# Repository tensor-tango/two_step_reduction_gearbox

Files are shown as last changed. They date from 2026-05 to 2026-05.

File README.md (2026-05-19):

# Project Overview
This project was developed as a portfolio engineering case study to demonstrate practical CAD design skills, mechanical reasoning and the ability to create employer-relevant engineering documentation.
The purpose of this project is not only to show a 3D model, but to demonstrate the practical value I can bring as an employee: designing mechanical parts, creating structured CAD assemblies, preparing technical drawings, documenting design assumptions, organizing a bill of materials and communicating engineering decisions clearly.
Used software: SOLIDWORKS

Below is the kinematic demonstration of the gearbox, with initial pinion speed of 100rpm
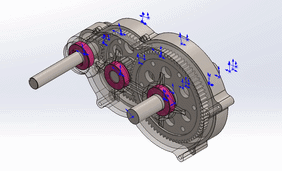
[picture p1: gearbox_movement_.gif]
Kinematics_demo


Below is one of the screenshots, which demonstrates the exploded view of the gearbox
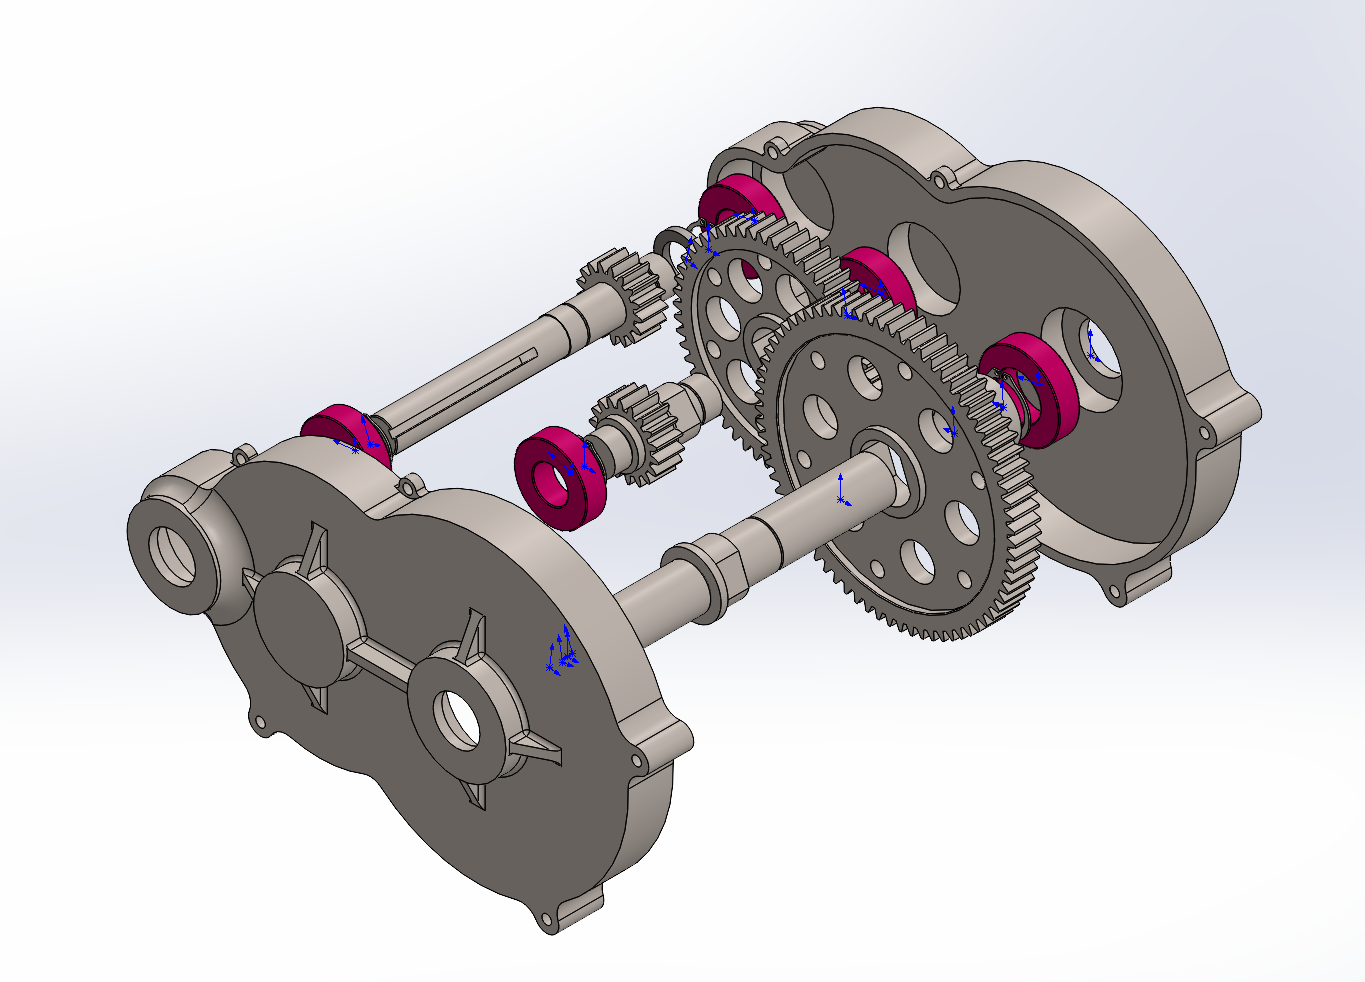
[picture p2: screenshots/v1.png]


Below is one of the blueprints, which demonstrates the technical drawing of lower housing part
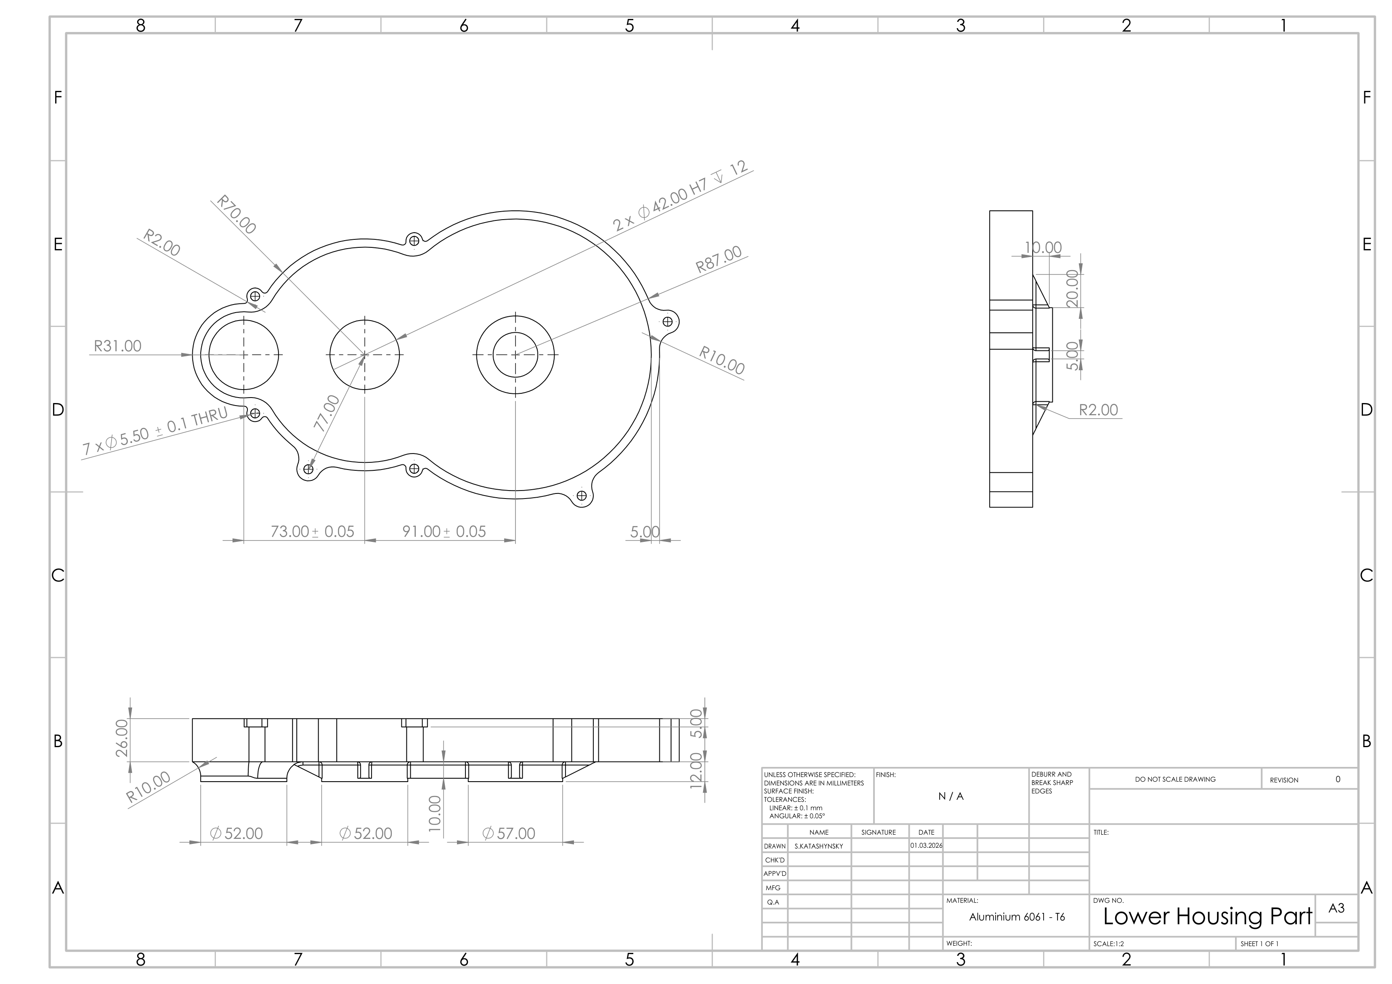
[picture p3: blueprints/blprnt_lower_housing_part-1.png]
Blueprint_demo


# Technical Notice
1. Actual bearings were replaced to the simplified bearing placeholders based on standard envelope dimensions
2. Material is assigned for CAD visualization only. Final material selection was not part of this study.
3. Actual ratio of the gearbox is 13.36:1, which gives 2.77% deviation from the target ratio
4. Normal internal clearance, standard precision and concept-level material assumptions were used.
5. Tight-fit for housing fastener bolts was assumed
6. Lubrication assumption: Lithium-EP 2

# BOM (Bill Of Materials)
| Item No. | Part Name | File Name | Qty. | Category | Material / Assumption | Notes |
|---:|---|---|---:|---|---|---|
| 1 | Lower housing part | `lower_part.SLDPRT` | 1 | Custom designed part | Aluminum 6061-T6 / aluminum alloy | Lower half of split gearbox housing |
| 2 | Upper housing part | `upper_part.SLDPRT` | 1 | Custom designed part | Aluminum 6061-T6 / aluminum alloy | Upper half of split gearbox housing |
| 3 | Gear A / input pinion, 17T | `gear_a.SLDPRT` | 1 | Custom gear | C45 steel / AISI 1045 steel | First-stage driving pinion, module 2 |
| 4 | Gear B / first-stage driven gear, 56T | `gear_b.SLDPRT` | 1 | Custom gear | C45 steel / AISI 1045 steel | First-stage driven gear, module 2 |
| 5 | Gear C / second-stage pinion, 18T | `gear_c.SLDPRT` | 1 | Custom gear | C45 steel / AISI 1045 steel | Second-stage driving pinion, module 2 |
| 6 | Gear D / output gear, 73T | `gear_d.SLDPRT` | 1 | Custom gear | C45 steel / AISI 1045 steel | Second-stage output gear, module 2 |
| 7 | Output shaft | `output_shaft.SLDPRT` | 1 | Custom shaft | C45 steel / AISI 1045 steeld | Supports output gear and transmits output torque |
| 8 | Output shaft spacer tube | `output_shaft_stopper_tube.SLDPRT` | 1 | Custom spacer | C45 steel / AISI 1045 steel | Axial positioning component |
| 9 | Third gear shaft spacer tube | `a_gear_shaft_stopper_tube.SLDPRT` | 1 | Custom spacer | C45 steel / AISI 1045 steel | Axial positioning component for intermediate shaft |
| 10 | Bearing placeholder 6004 | `cosmetic_bearing_20-42-12.SLDPRT` | 4 | Simplified standard component | Bearing steel | Standard envelope: 20×42×12 mm, CN |
| 11 | Bearing placeholder 6005 | `cosmetic_bearing_25-47-12.SLDPRT` | 4 | Simplified standard component | Bearing steel | Standard envelope: 25×47×12 mm, CN |
| 12 | Retaining ring for 20 mm shaft, DIN471 | `retaining_ring_1.SLDPRT` | 4 | Simplified standard component | Spring steel | Used for axial retention |
| 13 | Retaining ring for 25 mm shaft, DIN 471 | `retaining_ring_2.SLDPRT` | 2 | Simplified standard component | Spring steel | Used for axial retention |
| 14 | M5 hex head bolt | | 7 | Standard hardware | Steel, class 8.8, zinc-plated | Used to fasten upper and lower housing parts |
| 15 | M5 washer | |14 | Standard hardware | Steel, zinc-plated | Optional washer under bolt head |
| 16 | M5 hex nut | | 7 | Standard hardware | Steel, class 8.8,  zinc-plated | Required if the lower housing is not threaded |

# FEM-Studies
A simplified static FEM study was performed to visualize stress concentration in the gear tooth contact regions.
All of the gears were assigned to the material of "Plain Carbon Steel".

Below is one of the screenshots, which demonstrates the local tooth - stress conecetration for the first stage of the gearbox
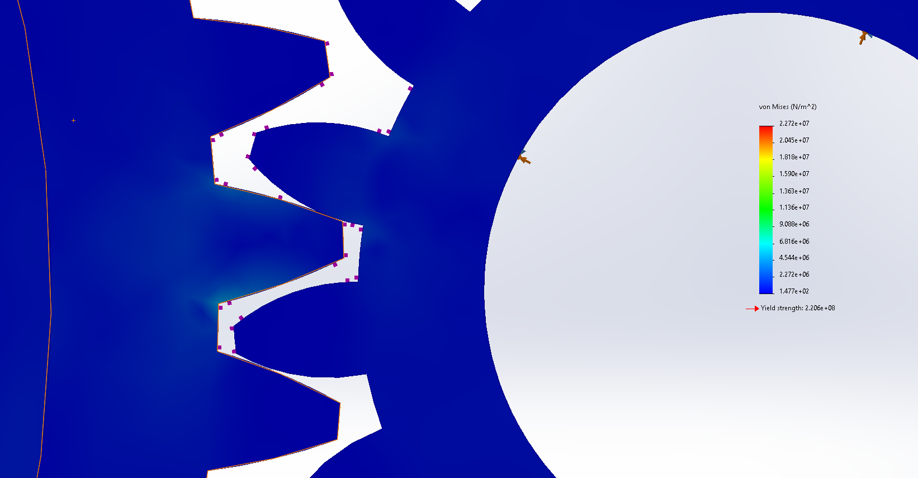
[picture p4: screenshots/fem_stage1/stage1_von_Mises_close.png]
Stress in stage 1


Below is one of the screenshots, which demonstrates the local tooth-stress conecetration for the second stage of the gearbox
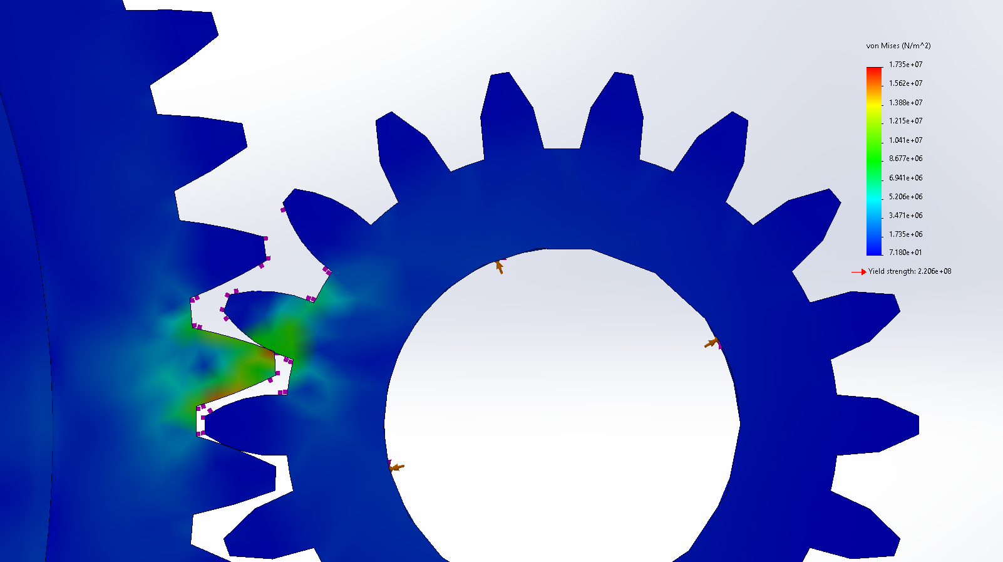
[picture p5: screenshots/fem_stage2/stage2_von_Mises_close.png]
Stress in stage 2


The full-view screenshots with the results of FEM-study for both of the stage can be found in './screenshots' folder. They include stress-concentration, displacement and strain.

| FEM Case | Load setup | Max von Mises | Yield strength | Safety Factor (FoS) |
|---|---|---|---|---|
| Stage 1 | 1 $N\cdot m$ torque on Gear A, Gear B constrained | 22.7 MPa | 220.6MPa | 9.7 |
| Stage 2 | 3.13 $N\cdot m$ torque on Gear C, Gear D constrained | 17.4 MPa | 220.6 MPa | 12.7 |

It was assumed the input torque 1 $N\cdot m$ on Gear A, so that in the second stage the Gear C has torque approx 3.13 $N\cdot m$.
According to this study, the maximal input torque could be  9.7 $N\cdot m$.
Below is the table of different possible input torques and safety levels

| Safety Factor (FoS) | Input Torque |
| --- | --- |
| FoS 1.0 | 9.7 $N\cdot m$ |
| FoS 1.5 | 6.5 $N \cdot m$ |
| FoS 2.0 | 4.85 $N \cdot m$ |
| FoS 3.0 | 3.2 $N\cdot m$|
| FoS 5.0| 1.9 $N\cdot m$ |

These FEM studies are simplified static torque/contact checks

# Bearings information
The bearing geometry in this project is simplified and used as placeholder geometry for CAD layout purposes.
The selected envelope dimensions correspond to standard deep groove ball bearings:
1. 6004: 20×42×12 mm
2. 6005: 25×47×12 mm

# Calculations
Gear ratio:
- Stage 1: 56 / 17 = 3.294
- Stage 2: 73 / 18 = 4.056
- Total ratio: 3.294 $\cdot$ 4.056 = 13.36:1
- Deviation from target 13:1 = +2.77%

Pitch diameter:
- $dA = 2 \cdot 17 = 34$ mm
- $dB = 2 \cdot 56 = 112$ mm
- $dC = 2 \cdot 18 = 36$ mm
- $dD = 2 \cdot 73 = 146$ mm

Center distances:
- $a_1 = \frac{dA + dB}{2} = \frac{34 + 112}{2} = 73$ mm
- $a_2 = \frac{dC + dD}{2} = \frac{36 + 146}{2} = 91$ mm

Output speed:
- $n_{out} = 100 / 13.36 = 7.485$ rpm

Simplified tangential tooth load estimation:
Assumption of Input Torque as $1Nm$
- $F_{tA} = 2 \cdot 1 / 0.034 = 58.8$ N
- $T_{intermediate} = 1 \cdot 3.294 \cdot 0.95 = 3.13$ Nm
- $F_{tC} = 2 × 3.13 / 0.036 = 173.9$ N

Radial gear force estimation:
- $F_{rA} = 58.8 \cdot tan(20°) = 21.4$ N
- $F_{rC} = 173.9 \cdot tan(20°) = 63.3$ N

Bearing reaction estimation (for the second stage):
- $F_{res} = (173.9² + 63.3²)^{1/2} = 185.1$ N

# Gears Info
Dimension are specified in mm and deg

Gear A (pinion):
1. No. of Teeth: 17
2. Module: 2
3. Pressure Angle: 20
4. Pitch diameter: 34
5. Outside diameter: 38
6. Root diameter: 29
7. Base diameter: 31.95
8. Face width: 15

Gear B:
1. No. of Teeth: 56
2. Module: 2
3. Pressure Angle: 20
4. Pitch diameter: 112
5. Outside diameter: 116
6. Root diameter: 107
7. Base diameter: 107
8. Face width: 15

Gear C:
1. No. of Teeth: 18
2. Module: 2
3. Pressure Angle: 20
4. Pitch diameter: 36
5. Outside diameter: 40
6. Root diameter: 31
7. Base diameter: 33.825
8. Face width: 15

Gear D:
1. No. of Teeth: 73
2. Module: 2
3. Pressure Angle: 20
4. Pitch diameter: 146
5. Outside diameter: 150
6. Root diameter: 140.98
7. Base diameter: 137.2
8. Face width: 15

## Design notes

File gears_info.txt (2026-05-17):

Dimension are specified in mm and deg

Gear A (pinion):
	No. of Teeth: 17
	Module: 2
	Pressure Angle: 20
	Pitch diameter: 34
	Outside diameter: 38
	Root diameter: 29
	Base diameter: 31.95
	Face width: 15

Gear B:
	No. of Teeth: 56
	Module: 2
	Pressure Angle: 20
	Pitch diameter: 112
	Outside diameter: 116
	Root diameter: 107
	Base diameter: 107
	Face width: 15

Gear C:
	No. of Teeth: 18
	Module: 2
	Pressure Angle: 20
	Pitch diameter: 36
	Outside diameter: 40
	Root diameter: 31
	Base diameter: 33.825
	Face width: 15

Gear D:
	No. of Teeth: 73
	Module: 2
	Pressure Angle: 20
	Pitch diameter: 146
	Outside diameter: 150
	Root diameter: 140.98
	Base diameter: 137.2
	Face width: 15

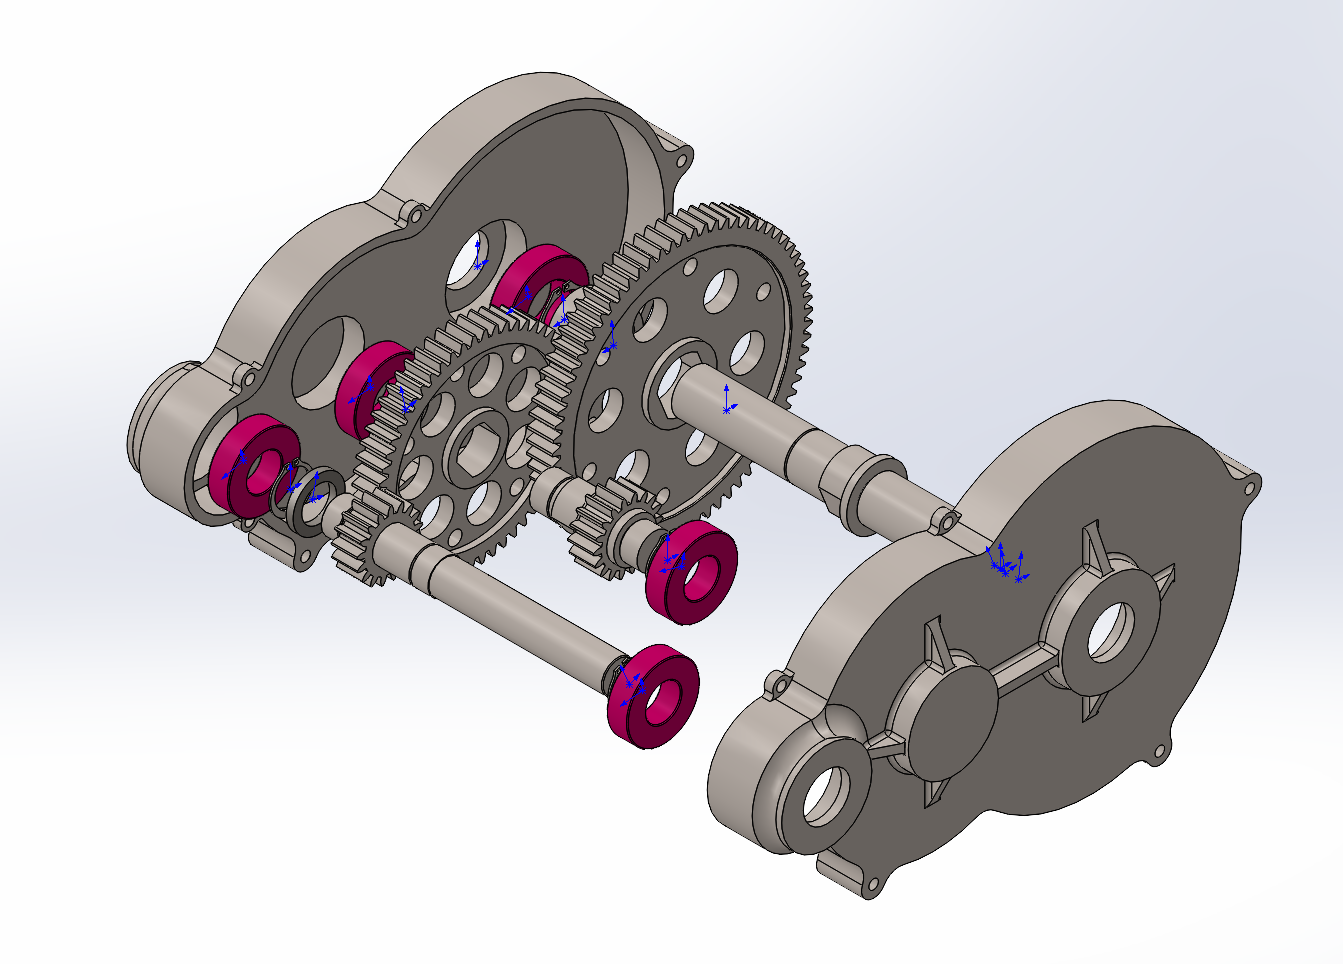
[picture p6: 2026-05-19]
screenshots/v3.png

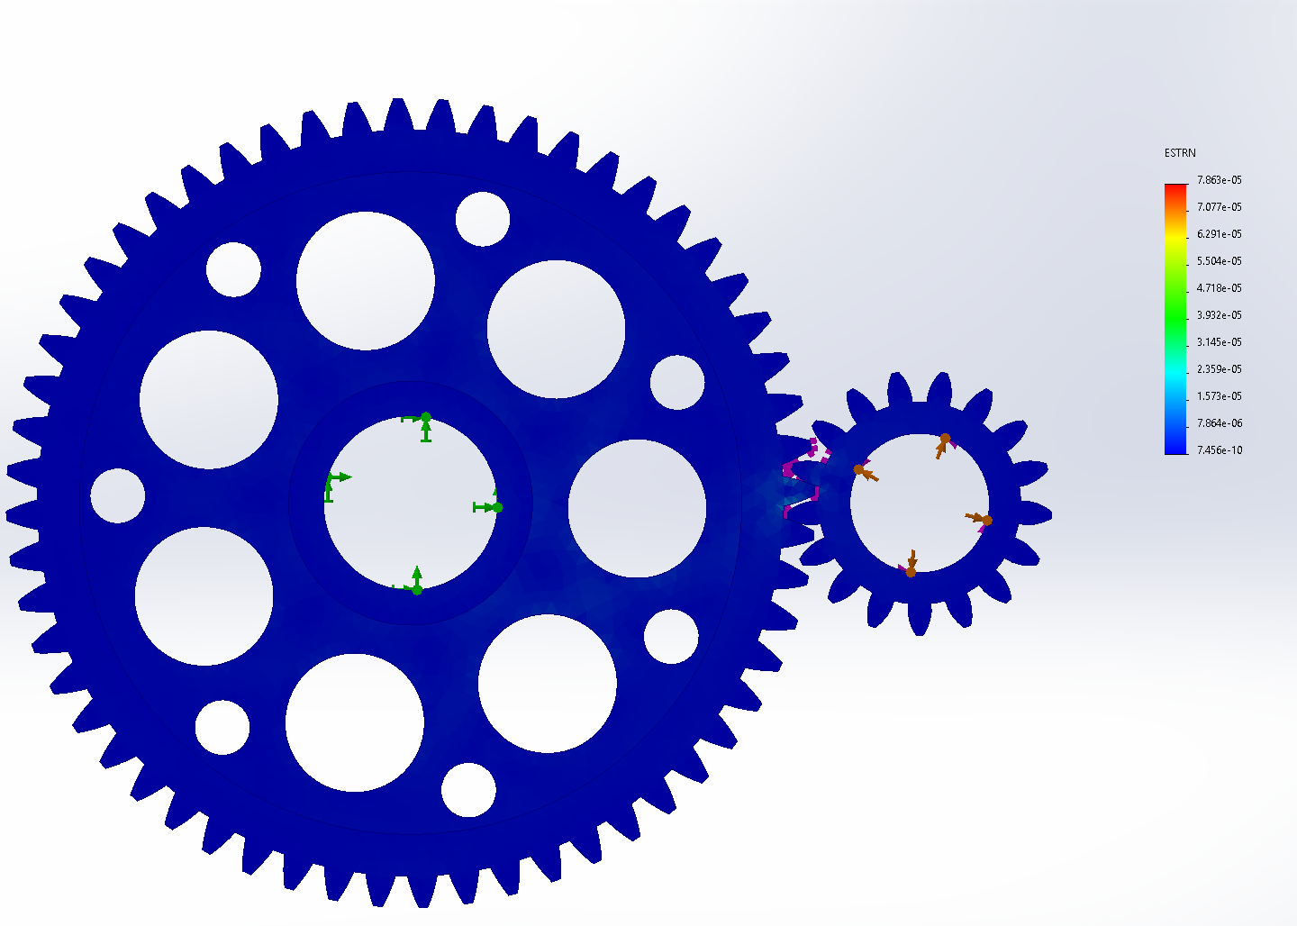
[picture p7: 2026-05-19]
screenshots/fem_stage1/stage1_strain.png

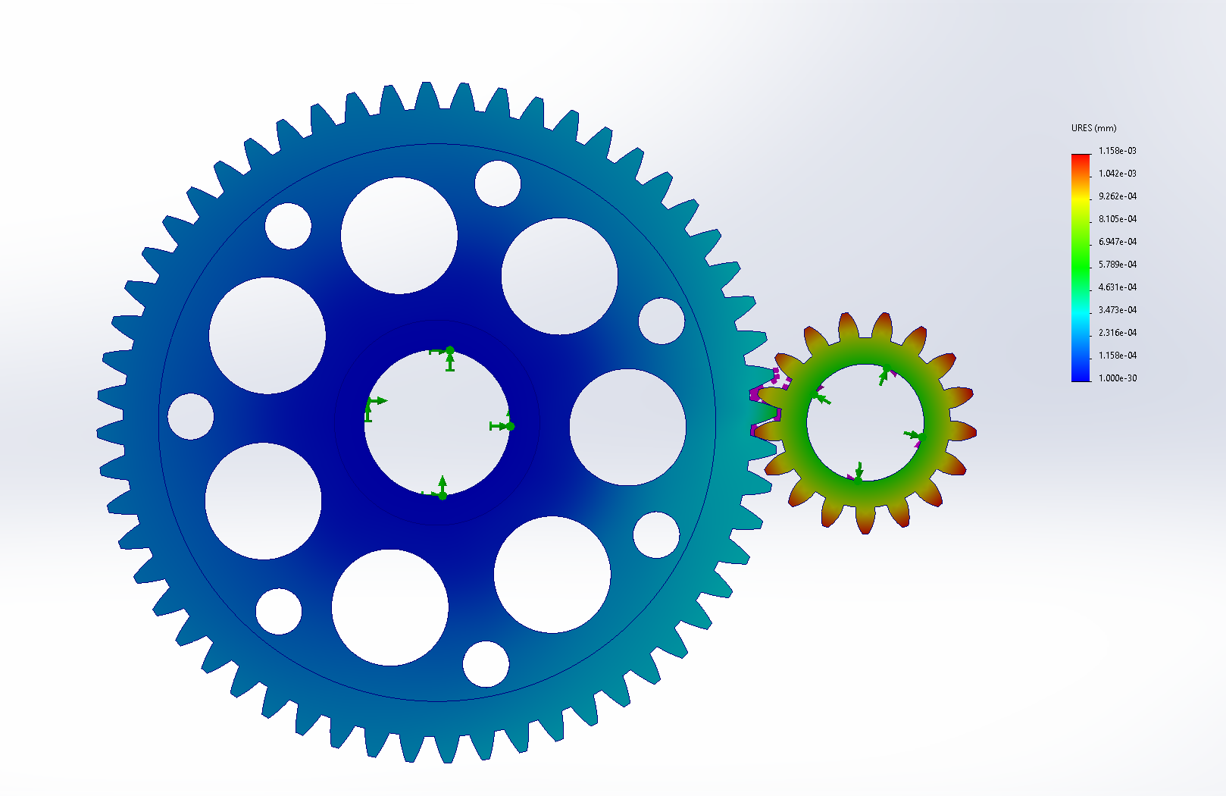
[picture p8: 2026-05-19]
screenshots/fem_stage1/stage1_displacement.png

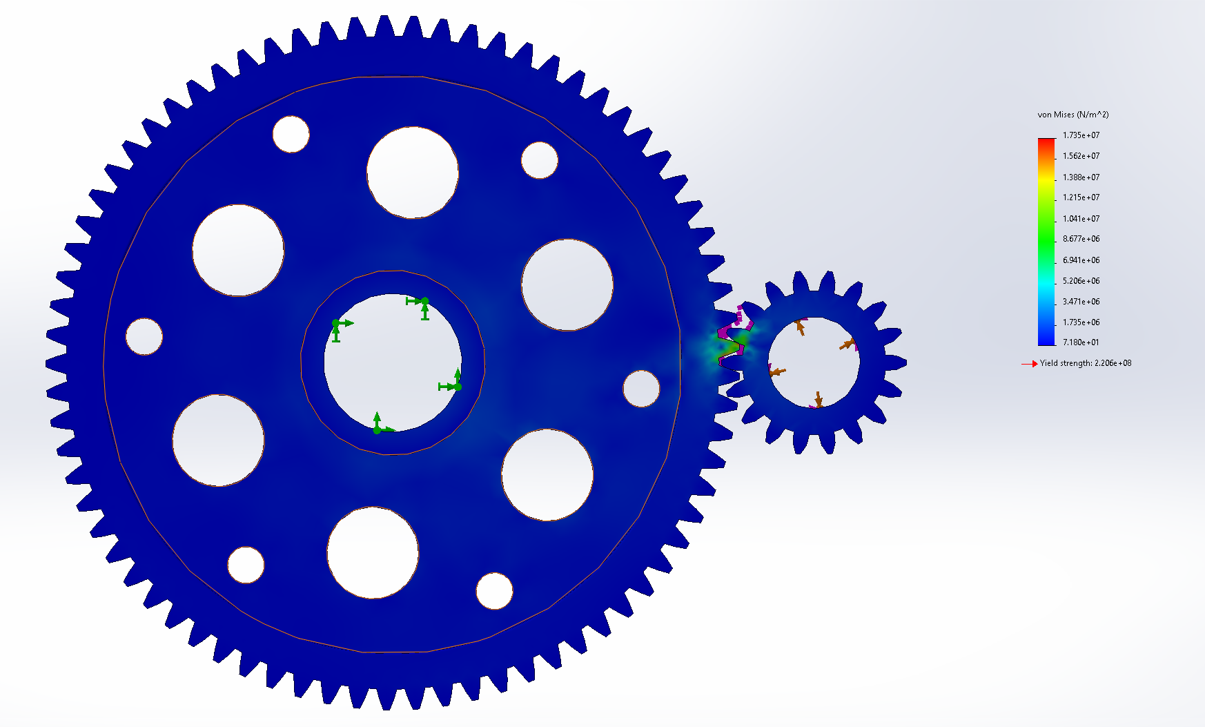
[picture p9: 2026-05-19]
screenshots/fem_stage2/stage2_von_Mises_global.png

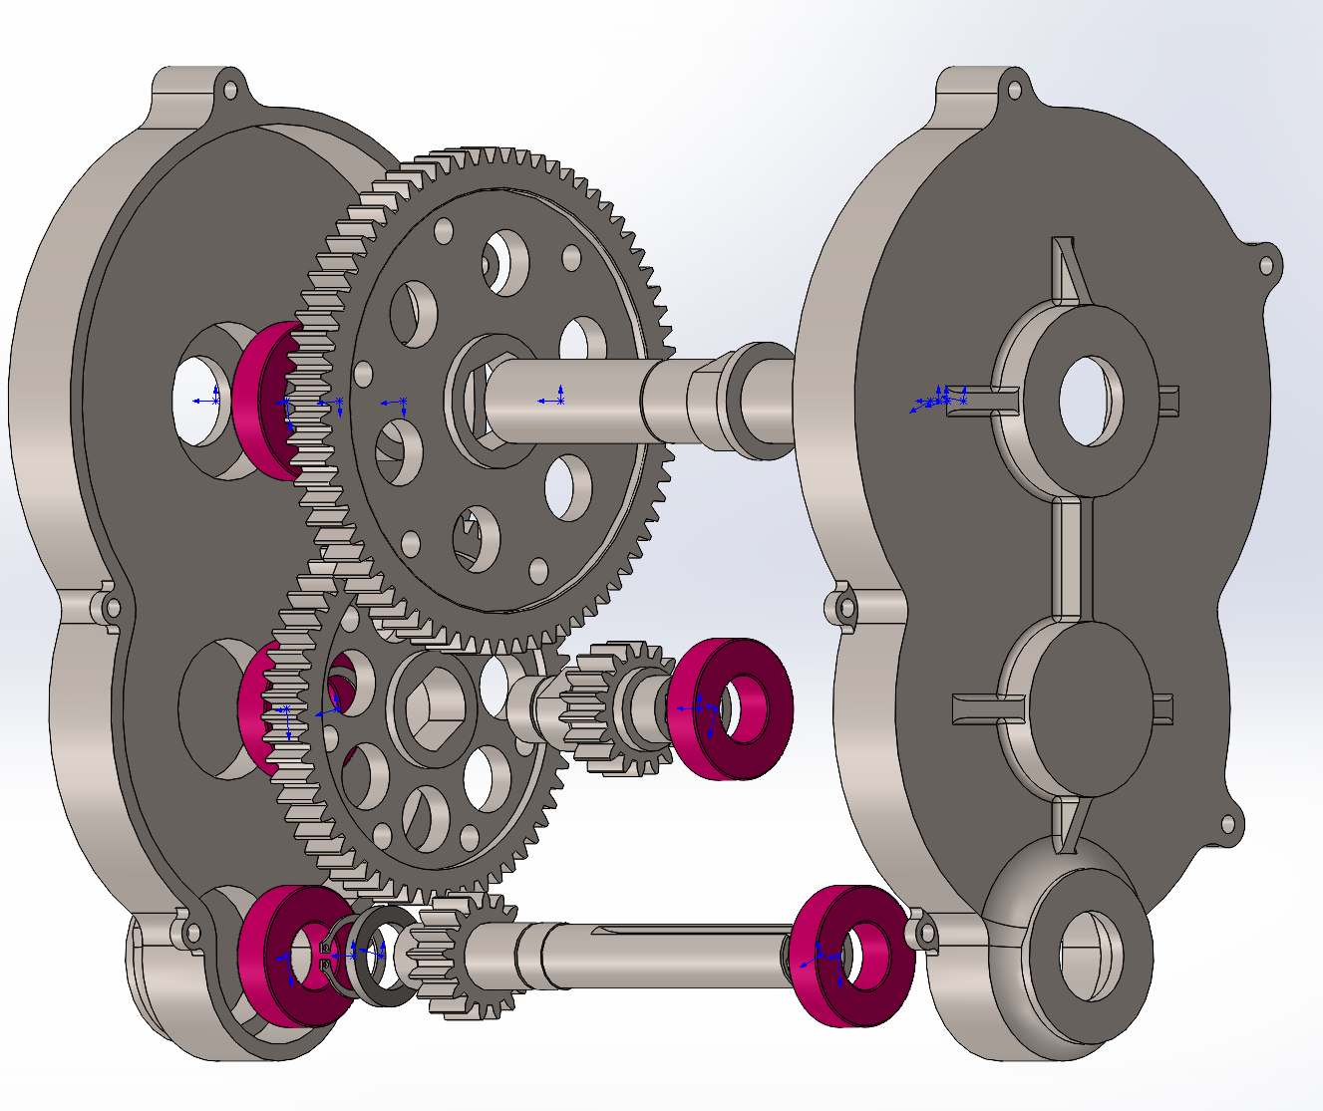
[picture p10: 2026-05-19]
screenshots/v2.png

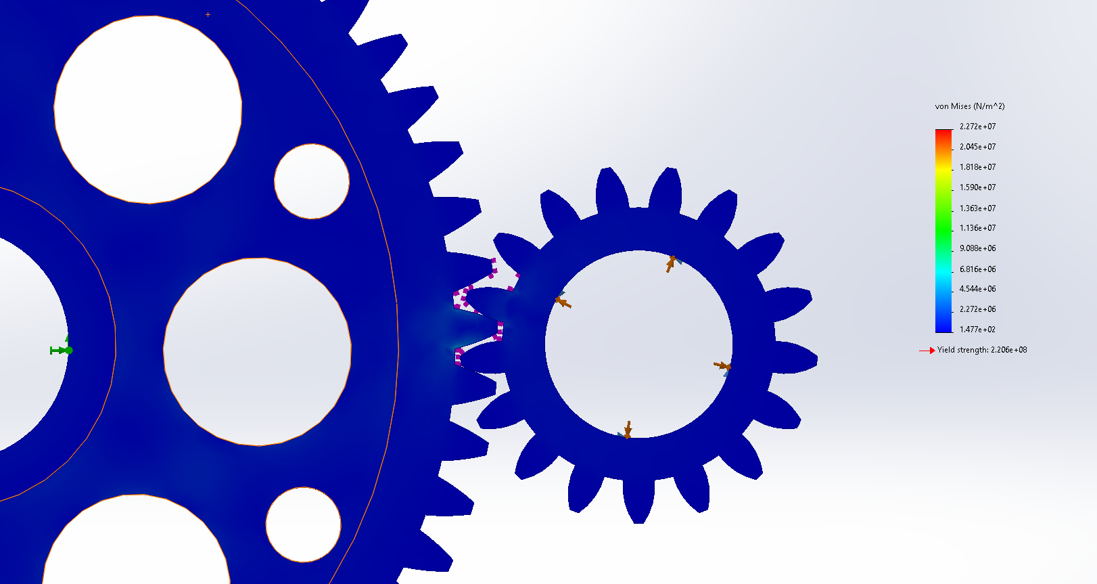
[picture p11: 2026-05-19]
screenshots/fem_stage1/stage1_von_Mises_global.png

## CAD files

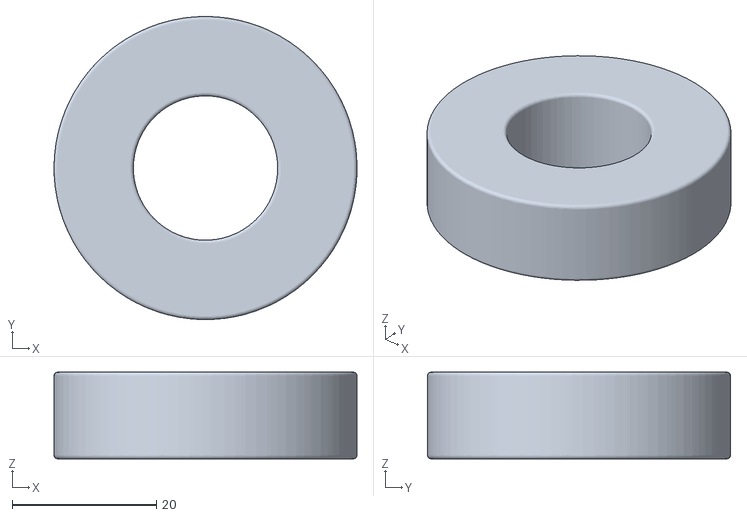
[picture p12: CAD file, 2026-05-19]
STL/gearbox_assembly - cosmetic_bearing_20-42-12-5.STL
42.0 x 42.0 x 12.0

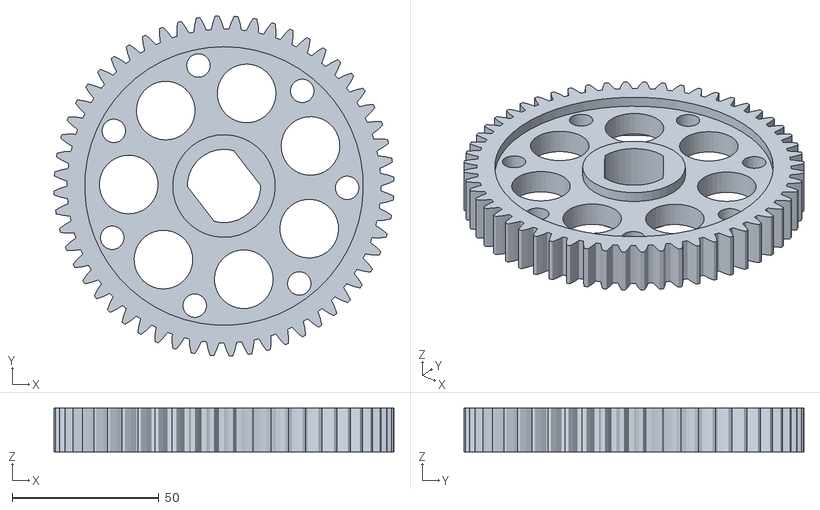
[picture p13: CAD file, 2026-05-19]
STL/gearbox_assembly - gear_b-3.STL
115.9 x 115.9 x 15.0

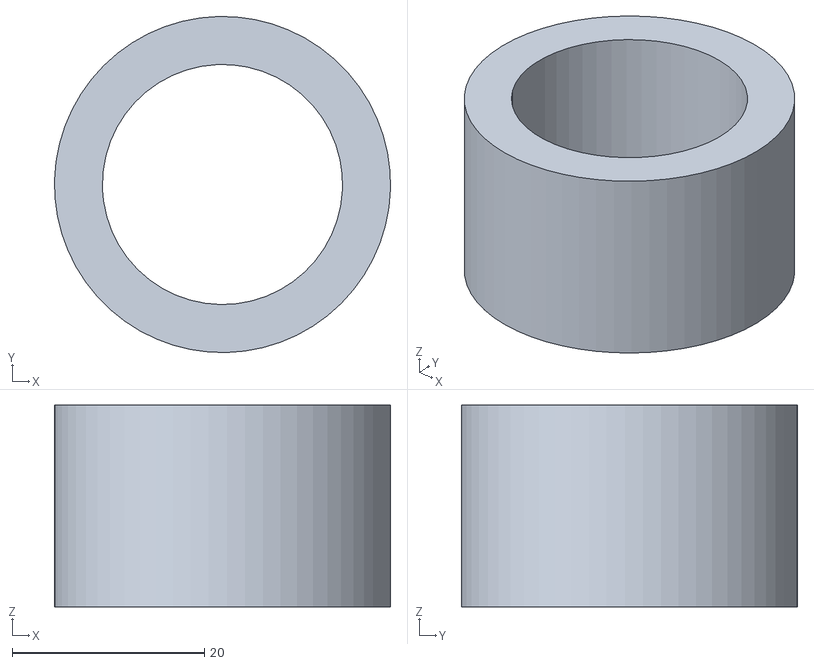
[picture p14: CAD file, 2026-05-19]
STL/gearbox_assembly - output_shaft_stopper_tube-1.STL
35.0 x 35.0 x 21.0

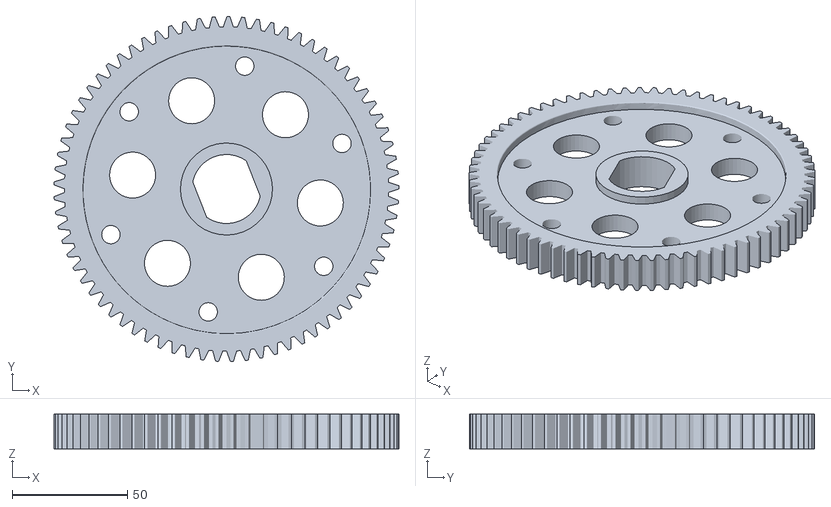
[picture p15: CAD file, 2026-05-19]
STL/gearbox_assembly - gear_d-5.STL
150.0 x 150.0 x 15.0

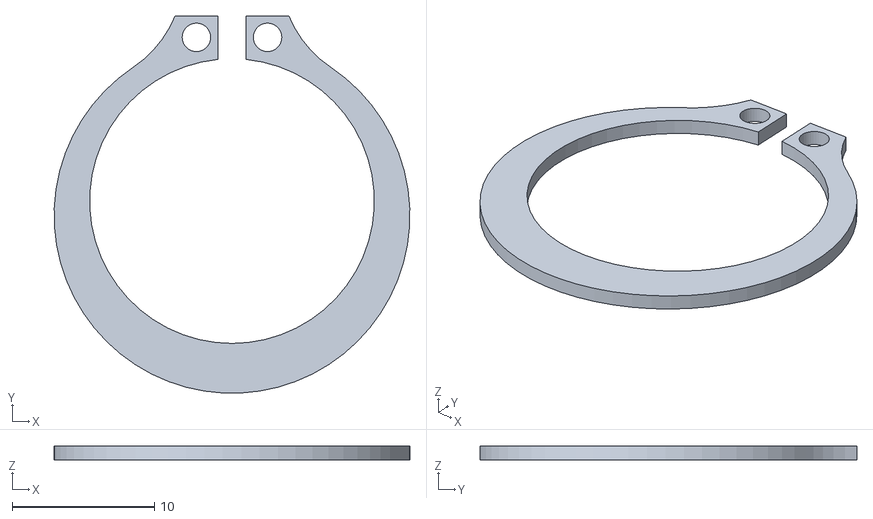
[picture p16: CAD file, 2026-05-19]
STL/gearbox_assembly - retaining_ring_20mm_shaft-2.STL
25.0 x 26.5 x 1.00

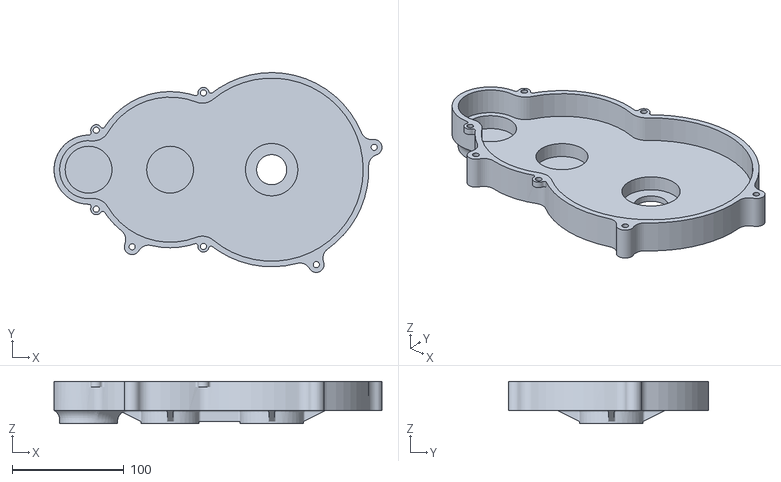
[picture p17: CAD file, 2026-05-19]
STL/gearbox_assembly - lower_housing_part-1.STL
293.8 x 179.1 x 38.0

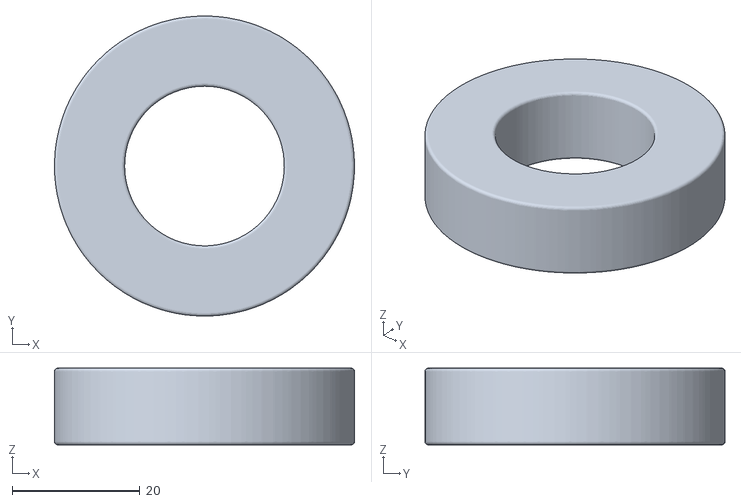
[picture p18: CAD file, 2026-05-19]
STL/gearbox_assembly - cosmetic_bearing_25-47-12-2.STL
47.0 x 47.0 x 12.0

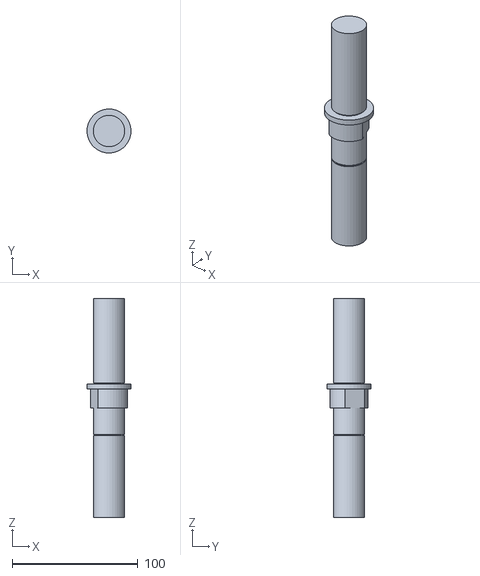
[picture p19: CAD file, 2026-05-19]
STL/gearbox_assembly - output_shaft-1.STL
35.0 x 35.0 x 174.0

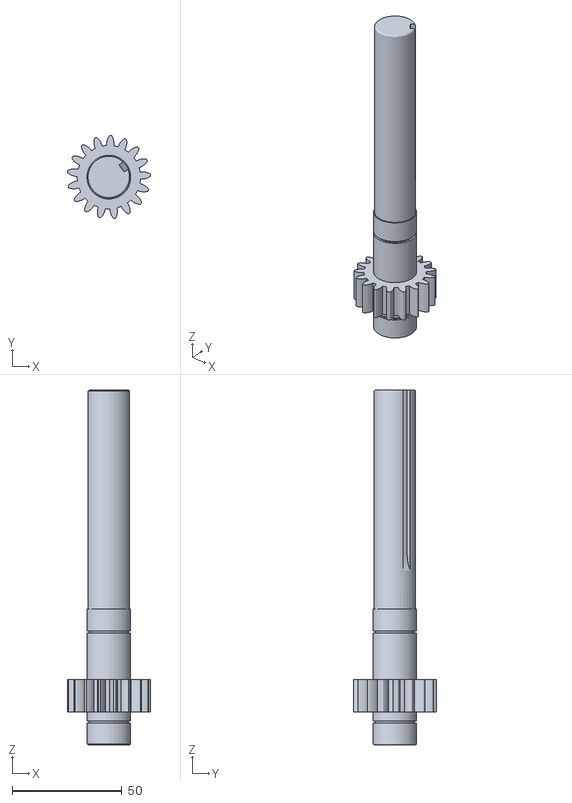
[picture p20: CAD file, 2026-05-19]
STL/gearbox_assembly - gear_a-3.STL
37.9 x 37.9 x 162.0

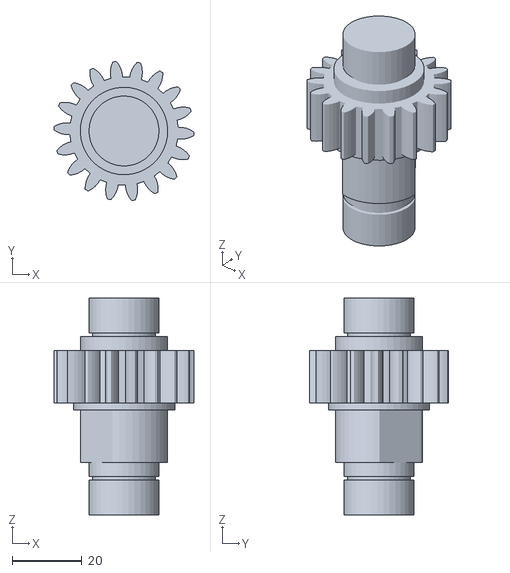
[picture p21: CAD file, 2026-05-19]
STL/gearbox_assembly - gear_c-4.STL
40.0 x 39.8 x 62.0

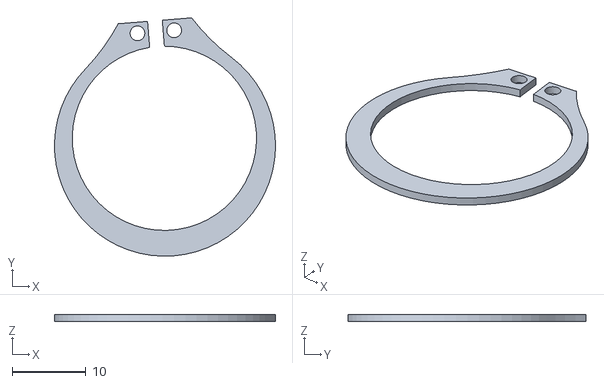
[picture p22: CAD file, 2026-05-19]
STL/gearbox_assembly - retaining_ring_25mm_shaft-1.STL
30.0 x 32.3 x 1.00

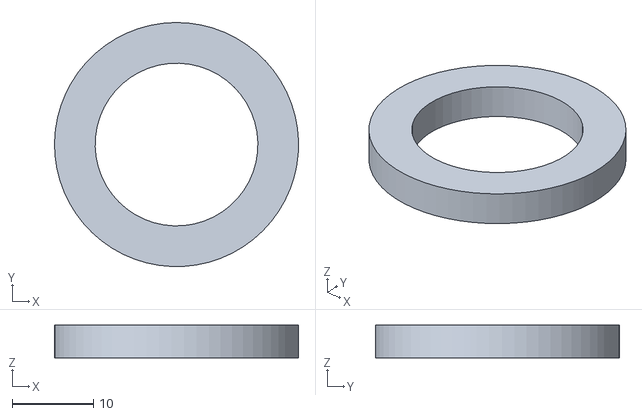
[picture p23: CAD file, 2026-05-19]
STL/gearbox_assembly - a_gear_shaft_stopper_tube-1.STL
30.0 x 30.0 x 4.00

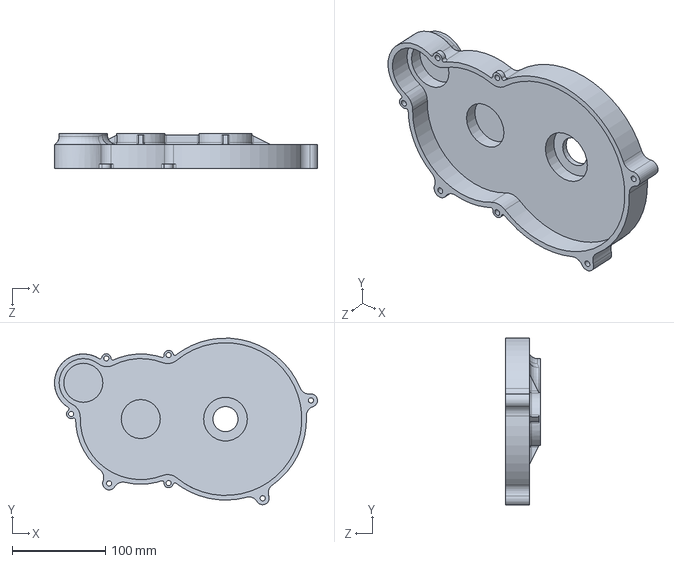
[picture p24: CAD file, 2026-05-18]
Parts/lower_housing_part.SLDPRT
282.5 x 178.9 x 38.0 mm

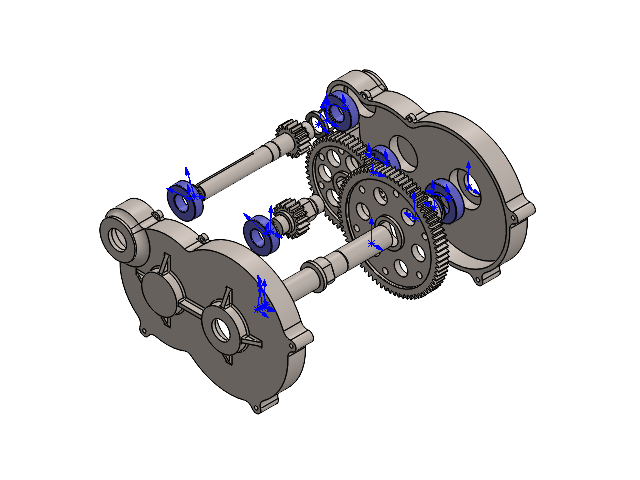
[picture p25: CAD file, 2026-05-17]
gearbox_assembly.SLDASM
lower_part
cosmetic_bearing_20-42-12 x 4
cosmetic_bearing_25-47-12 x 2
gear_a
retaining_ring_1 x 4
3rd_gear_shaft_stopper_tube
gear_b
gear_c
gear_d
output_shaft_stopper_tube
output_shaft
retaining_ring_2 x 2
upper_part

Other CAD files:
STL/gearbox_assembly - upper_housing_part-1.STL
Parts/upper_housing_part.SLDPRT
Parts/retaining_ring_20mm_shaft.SLDPRT
Parts/output_shaft.SLDPRT
Parts/a_gear_shaft_stopper_tube.SLDPRT
Parts/cosmetic_bearing_20-42-12.SLDPRT
Parts/cosmetic_bearing_25-47-12.SLDPRT
Parts/gear_a.SLDPRT
Parts/gear_b.SLDPRT
Parts/gear_c.SLDPRT
Parts/gear_d.SLDPRT
Parts/output_shaft_stopper_tube.SLDPRT
Parts/retaining_ring_25mm_shaft.SLDPRT
blueprints/lower_housing_part_blprnt.SLDDRW

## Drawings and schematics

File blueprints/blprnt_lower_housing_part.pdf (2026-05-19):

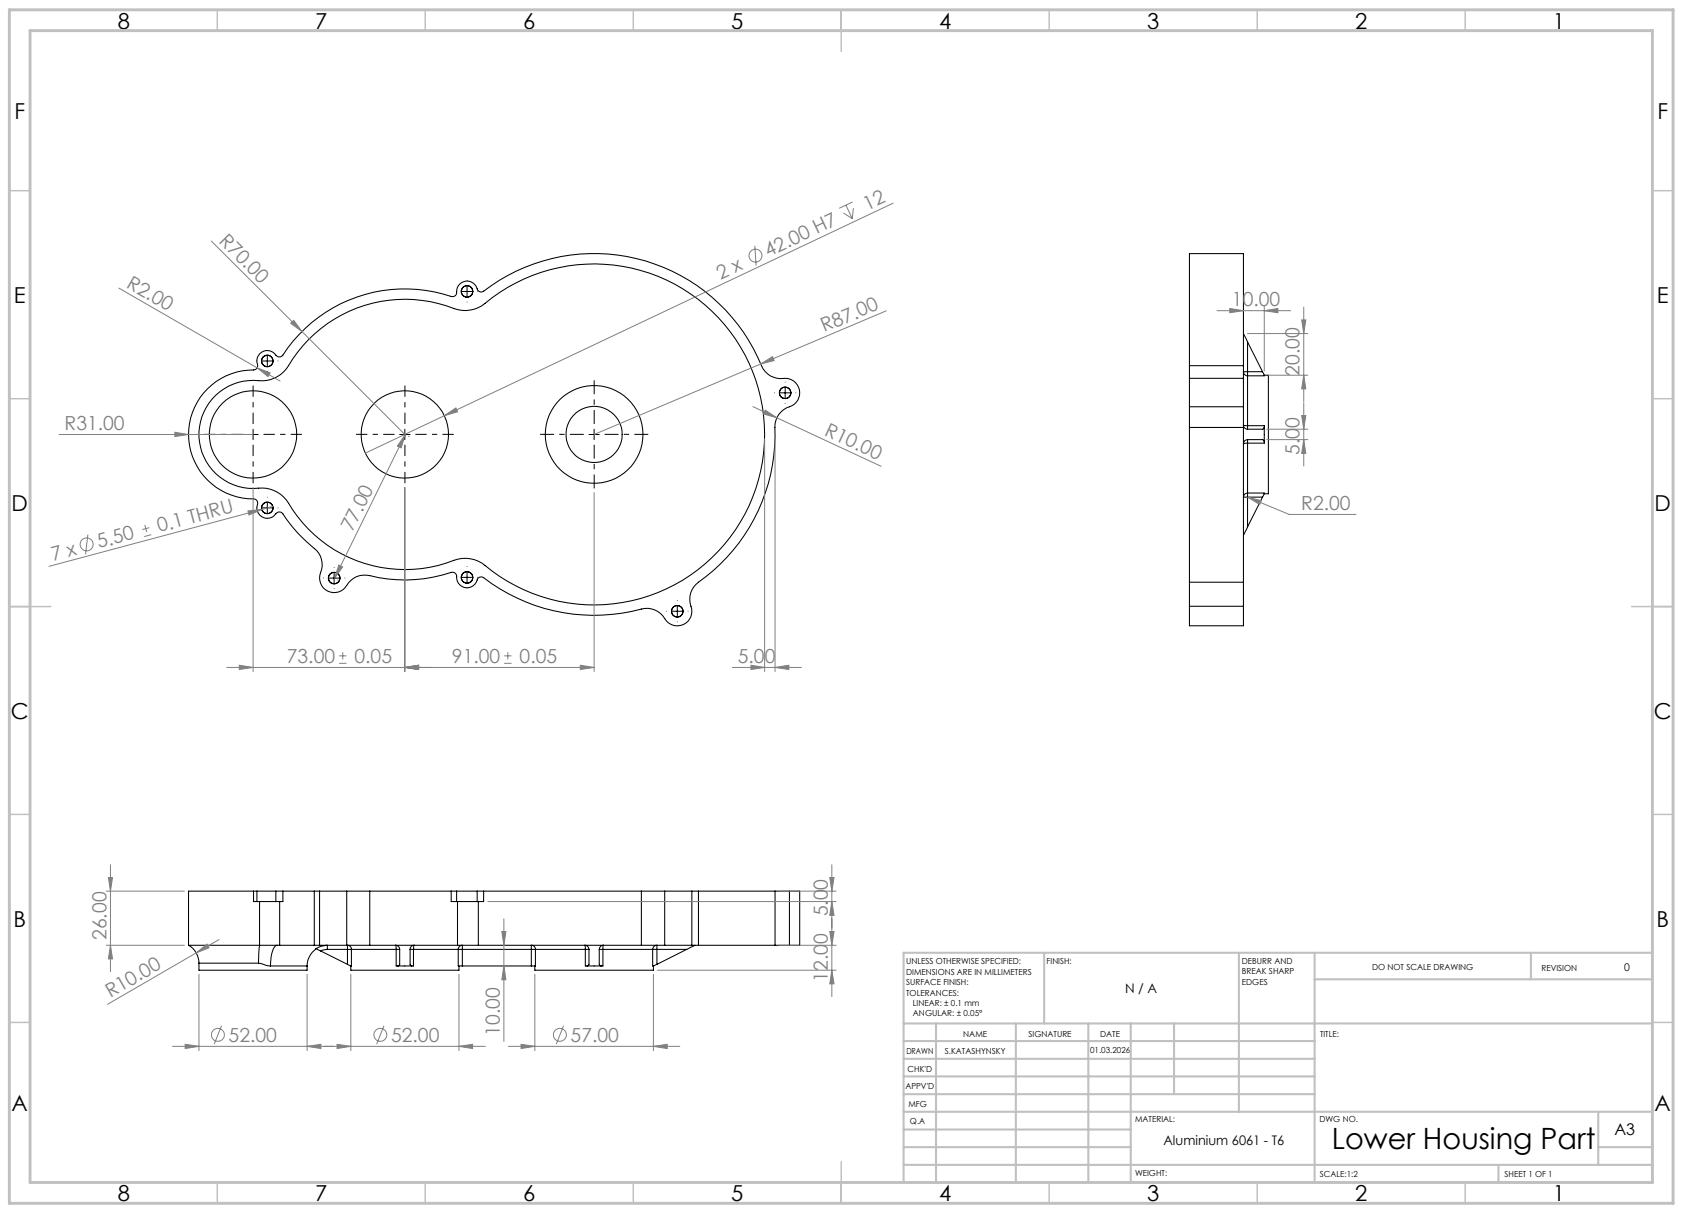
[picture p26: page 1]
7 x 5.50 0.1 THRU; FINISH:; DEBURR AND; BREAK SHARP; DO NOT SCALE DRAWING; REVISION; SCALE:1:2; SHEET 1 OF 1

UNLESS OTHERWISE SPECIFIED:
DIMENSIONS ARE IN MILLIMETERS
SURFACE FINISH:
TOLERANCES:
LINEAR: ± 0.1 mm
ANGULAR: ± 0.05°

NAME | SIGNATURE | DATE | | | | TITLE:

DRAWN | S.KATASHYNSKY | | 01.03.2026
CHK'D
APPV'D
MFG
Q.A | | | | MATERIAL: | DWG NO. Lower Housing Part | A3 Aluminium 6061 - T6

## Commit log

2026-05-17 Update README with actual gearbox ratio
2026-05-17 Enhance README with gearbox specifications and images
    Added technical details and blueprints for gearbox components.
2026-05-17 Change blueprint image for lower housing part
    Updated the blueprint image reference for the lower housing part.
2026-05-17 Revise gearbox description and gear specifications
    Updated the README to improve clarity and formatting.
2026-05-18 Enhance README with technical details and BOM
    Added technical notice, BOM, bearing information, and gear calculations sections to README.
2026-05-18 Fix formatting of gear calculations in README
2026-05-18 Fix formatting of M5 hex nut description in README
2026-05-19 Remove lower housing part blueprint from README
    Removed the blueprint image of the lower housing part from the README.
2026-05-19 Enhance README with gearbox demo and screenshot
    Added kinematic demonstration and exploded view screenshot.
2026-05-19 Update FEM studies section with gear material details
    Added information about gear material in FEM studies section.
